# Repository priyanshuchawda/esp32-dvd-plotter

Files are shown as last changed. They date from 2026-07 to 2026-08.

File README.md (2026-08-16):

# ESP32 / Uno DVD Pen Plotter

DVD-drive sleds on an **HW-130 L293D** shield. Both boards are supported in
separate folders — swap hardware, keep the same G-code tools.

| Doc | Contents |
| --- | --- |
| [`docs/STATUS.md`](docs/STATUS.md) | Done vs left checklist |
| [`docs/ARCHITECTURE.md`](docs/ARCHITECTURE.md) | How the system fits together |
| [`FINDINGS.md`](FINDINGS.md) | Measured bed, steps/mm, coil ohms |
| [`hardware/WIRING.md`](hardware/WIRING.md) | **ESP32 jumper wiring** (no soldering) |
| [`cad/pcb/`](cad/pcb/) | **ESP32↔HW-130 adapter PCB** (Uno-style stack + Gerbers) |
| [`src/README.md`](src/README.md) | Firmware folder map |

Pipeline

## Firmware folders

| Path | Board |
| --- | --- |
| [`src/uno/uno_plotter`](src/uno/uno_plotter/) | Arduino Uno (shield stacked) |
| [`src/esp32/esp32_plotter`](src/esp32/esp32_plotter/) | ESP32 (jumpers into shield headers) |

Bed: **55 × 50 mm** · steps/mm: **2.058** · baud: **115200**

## ESP32 quick start (current focus)

1. Shield **off** the Uno. Power shield `5V`+`GND` and `EXT_PWR` (yellow jumper
   off). Common GND with ESP32. See [`hardware/WIRING.md`](hardware/WIRING.md).
2. Eight jumpers: D12/D4/D7/D8 + D11/D3/D6/D5 → ESP32 GPIOs in the wiring table.
3. Flash and test:

```bash
arduino-cli compile -b esp32:esp32:esp32 src/esp32/esp32_plotter
arduino-cli upload  -b esp32:esp32:esp32 -p /dev/ttyUSB0 src/esp32/esp32_plotter

# USB serial: $COILTEST then raise $POWER= if needed
tools/send_gcode.py -p /dev/ttyUSB0 -b 115200 test-square-uno.gcode
```

Wi-Fi hotspot `DVD-Plotter` / `plotter123` → draw in the browser.

## Uno quick start

```bash
arduino-cli compile -b arduino:avr:uno src/uno/uno_plotter
arduino-cli upload  -b arduino:avr:uno -p /dev/ttyACM0 src/uno/uno_plotter
tools/send_gcode.py -p /dev/ttyACM0 -b 115200 test-square-uno.gcode
```

## Making G-code

| Tool | Use |
| --- | --- |
| [`tools/text2gcode.py`](tools/text2gcode.py) | Hershey single-stroke text |
| [`tools/handwriting2gcode.py`](tools/handwriting2gcode.py) | Neural handwriting |
| [`tools/image2gcode.py`](tools/image2gcode.py) | Bitmap → outlines |
| [`tools/send_gcode.py`](tools/send_gcode.py) | USB stream |
| `python3 sim/simulate.py job.gcode --paper` | Paper preview |

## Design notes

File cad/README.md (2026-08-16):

# Mechanical CAD

[`plotter.scad`](plotter.scad) is a parametric model of the whole machine.
[`pcb/`](pcb/) is the **ESP32 ↔ HW-130 adapter** KiCad project (Uno-form stack).

Bed defaults match this build’s measurements (**55 × 50 mm**). Other sled
dimensions are still estimates — measure your chassis before cutting or
printing.

## Render and export

```bash
mkdir -p cad/out

# Whole machine (PNG)
openscad -D 'part="assembly"' --imgsize=1200,900 \
  --camera=120,110,70,55,0,30,480 \
  -o cad/out/assembly.png cad/plotter.scad

# Printable parts
openscad -D 'part="pen_lift"' -o cad/out/pen_lift.stl cad/plotter.scad
openscad -D 'part="paper_bed"' -o cad/out/paper_bed.stl cad/plotter.scad
openscad -D 'part="gantry_upright"' -o cad/out/gantry_upright.stl cad/plotter.scad
```

Valid `part` values: `assembly`, `pen_lift`, `paper_bed`, `gantry_upright`.

Confirm manifold solids after edits:

```bash
openscad -D 'part="pen_lift"' -o /tmp/check.stl cad/plotter.scad 2>&1 | grep Simple
```

`Simple: yes` means a valid printable solid.

## Layout

Y sled moves the paper front/back; X sled is overhead and moves the pen
left/right. Usable drawing area is the paper bed: **55 × 50 mm** on this frame
(`sled_travel_x` / `sled_travel_y` / `bed_x` / `bed_y` in the SCAD file).

## Pen bracket

Bolts to the X carriage and hangs down. Guide tube, SG90 cradle, and screw
strip are stacked so they do not overlap. A rubber band can provide pen
down-force; the servo horn lifts the collar.

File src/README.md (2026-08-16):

# Firmware layout

| Path | Board | Notes |
| --- | --- | --- |
| [`uno/uno_plotter`](uno/uno_plotter/) | Arduino Uno | Stock AFMotor + HW-130 (stacked) |
| [`uno/uno_motor_test`](uno/uno_motor_test/) | Arduino Uno | Jog / bring-up |
| [`esp32/esp32_plotter`](esp32/esp32_plotter/) | ESP32 | 74HC595 via jumpers — **active ESP path** |
| [`esp32/legacy_bypass`](esp32/legacy_bypass/) | ESP32 | Old solder-bypass firmware (archived) |

Wiring for ESP32 jumpers: [`../hardware/WIRING.md`](../hardware/WIRING.md).

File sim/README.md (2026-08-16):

# Simulation

Two independent layers. The first needs nothing but Python; the second emulates
the real ESP32 running the actual compiled binary.

## Layer 1: toolpath simulation (no hardware, no accounts)

`firmware_model.py` is a line-by-line port of the motion logic in
[`../src/esp32_l293d_plotter.ino`](../src/esp32_l293d_plotter.ino): the same
Bresenham interleave, the same `lroundf` step rounding, the same four-phase
coil table. The Uno plotter uses the same G-code dialect and Bresenham idea, so
the same preview works for Uno jobs if you pass the calibrated steps/mm.

**Uno defaults (measured):** bed 55×50 mm, **2.058** steps/mm on X and Y.

```bash
# Uno square (current hardware)
python3 sim/simulate.py test-square-uno.gcode \
  --envelope 55 --steps-x 2.058 --steps-y 2.058 \
  --out sim/out/uno_square.png

# Any job — always match firmware $STEPSX/$STEPSY and bed
python3 sim/simulate.py myart.gcode \
  --envelope 55 --steps-x 2.058 --steps-y 2.058 \
  --out sim/out/preview.png
```

It writes a PNG to `sim/out/` showing the drawn path, the pen-up travel moves,
the usable envelope, and the coil waveforms. It exits non-zero and prints
warnings when a job leaves the envelope, ends with the pen down, or uses a
command the firmware would reject.

Use it before sending any new artwork to real hardware. It costs nothing and
catches scaling and travel mistakes that would otherwise crash the carriage
into an end stop.

**Keep this file in sync with the firmware.** If the motion code changes, the
model must change too, or the simulation stops being meaningful.

## Layer 2: firmware emulation (Wokwi)

This runs the actual compiled binary on an emulated ESP32 and captures the real
GPIO transitions, so it validates the shipped firmware rather than a model of
it. Relevant once you leave the Uno path.

Install once:

```bash
curl -sSL https://wokwi.com/ci/install.sh | sh
```

It needs a free token from <https://wokwi.com/dashboard/ci>:

```bash
export WOKWI_CLI_TOKEN=your_token_here
```

Build, stage the binary, then run:

```bash
arduino-cli compile --fqbn esp32:esp32:esp32 --build-path /tmp/esp32-dvd-plotter-build .
mkdir -p build
cp /tmp/esp32-dvd-plotter-build/esp32-dvd-plotter.ino.{merged.bin,elf} build/
wokwi-cli . --timeout 10000 --serial-log-file build/serial.log
```

[`../diagram.json`](../diagram.json) wires a logic analyzer to the eight
direction GPIOs, so `--vcd-file` exports the real coil waveforms for inspection:

```bash
wokwi-cli . --timeout 20000 --vcd-file build/coils.vcd
```

`wokwi-cli lint` validates the diagram without a token. It already caught that
GPIO16 and GPIO17 are exposed as `RX2` and `TX2` on a 30-pin DevKit.

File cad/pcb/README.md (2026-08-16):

# ESP32 ↔ HW-130 adapter PCB

Uno-form adapter so the **HW-130 stacks like on an Arduino Uno**, while the
**ESP32-DevKit** plugs in beside it (right wing — not under the shield).

| | |
| --- | --- |
| KiCad project | [`esp32_hw130_adapter/`](esp32_hw130_adapter/) |
| Regenerator | [`generate_adapter.py`](generate_adapter.py) |
| Gerbers | [`out/gerbers.zip`](out/gerbers.zip) |
| Preview | [`out/adapter_top.png`](out/adapter_top.png) |
| Pin map | [`out/pinmap.md`](out/pinmap.md) |
| BOM | [`BOM.md`](BOM.md) |

**Board size ≈ 121 × 94 mm · 2-layer · DRC clean (0 errors)**

## How it works

```text
┌─────────────────────────────┬──────────────────────┐
│  Arduino R3 male headers    │  ESP32 DevKit        │
│  HW-130 stacks here         │  2×15 female sockets │
│  (same as Uno)              │  USB ↑               │
│                             │                      │
│  J_5V ── external 5 V       │                      │
└─────────────────────────────┴──────────────────────┘
```

Traces match firmware [`src/esp32/esp32_plotter`](../../src/esp32/esp32_plotter/):

| Shield | ESP32 |
| --- | --- |
| D12 | GPIO18 |
| D4 | GPIO19 |
| D7 | GPIO23 |
| D8 | GPIO13 |
| D11 | GPIO25 |
| D3 | GPIO26 |
| D6 | GPIO27 |
| D5 | GPIO32 |
| D10 (SERVO_1) | GPIO33 |
| 5V / GND | J_5V only |

## Open / rebuild

```bash
# GUI
kicad cad/pcb/esp32_hw130_adapter/esp32_hw130_adapter.kicad_pro

# Regenerate PCB from script (needs KiCad’s python3.14 + pcbnew)
python3.14 cad/pcb/generate_adapter.py
```

## Order / assemble

1. Upload [`out/gerbers.zip`](out/gerbers.zip) to any PCB fab (JLCPCB, PCBWay, …).
2. Solder parts from [`BOM.md`](BOM.md).
3. Plug ESP32 into the wing; stack HW-130 on the left headers.
4. Remove yellow **PWR** jumper; motors on `EXT_PWR`; logic 5 V into **J_5V**.
5. Flash `src/esp32/esp32_plotter` and run `$COILTEST`.

Until the PCB arrives, use Dupont jumpers — same nets — see
[`hardware/WIRING.md`](../../hardware/WIRING.md).

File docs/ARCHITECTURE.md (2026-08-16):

# Architecture

How the pieces connect on the **current Uno path**, and what is deferred.

## System overview

```mermaid
flowchart TB
  subgraph host [Laptop]
    T[text2gcode / handwriting2gcode / image2gcode]
    S[sim/simulate.py --paper]
    U[send_gcode.py]
    T --> S
    S -->|PNG looks good| U
  end

  subgraph controller [Arduino Uno]
    F[uno_plotter firmware]
    AF[AFMotor + 74HC595]
    F --> AF
  end

  subgraph machine [DVD frame]
    X[X sled M1/M2]
    Y[Y sled M3/M4]
    P[SG90 SERVO_1 optional]
  end

  U -->|USB 115200| F
  AF --> X
  AF --> Y
  F --> P
```

## Software pipeline

```mermaid
flowchart LR
  A[Text / image / strokes] --> B[G-code]
  B --> C{simulate.py}
  C -->|warnings| A
  C -->|ok| D[send_gcode.py]
  D --> E[Uno plotter]
  E --> F[Sleds move]
```

## Coordinate system

```text
Y 50 mm
^
|
|   paper / bed 55 × 50 mm
|
+--------------> X 55 mm
(0,0) = corner where sleds are parked at power-on / G92
```

Origin is a **corner**, not the middle of the rails.

## Firmware roles

| Sketch | Baud | Use |
| --- | --- | --- |
| `src/uno_motor_test` | 9600 | Manual jog / wiring bring-up |
| `src/uno/uno_plotter` | 115200 | Uno + stacked HW-130 |
| `src/esp32/esp32_plotter` | 115200 + WiFi | ESP32 jumpers → 74HC595 (no solder) |

## Deferred ESP32 path

```mermaid
flowchart TB
  Phone[Phone browser WiFi UI] --> ESP[ESP32 firmware]
  ESP -->|GPIO to L293D| DRV[HW-130 L293D]
  ESP -.->|D7 tied to 5V| OFF[74HC595 outputs Hi-Z]
  DRV --> MOTORS[X/Y steppers]
```

Do not start this until Uno ink plots are satisfactory. Tying `D7`→`5V`
disables the stock AFMotor path.

## CAD vs simulation

| Artifact | Answers |
| --- | --- |
| `cad/plotter.scad` | Will the frame / pen bracket fit? |
| `sim/simulate.py` | Will this G-code fit the bed and look right? |
| `sim/spice/` | Is coil current safe at a given step rate? |
| Watching sleds (no pen) | Do motors move / directions correct? |

Ink appearance without paper ≈ `simulate.py --paper`.

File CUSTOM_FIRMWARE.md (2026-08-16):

# Custom ESP32 firmware

> **Active sketch:** [`src/esp32/esp32_plotter`](src/esp32/esp32_plotter/) —
> drives the HW-130 **74HC595 with jumper wires** (no soldering).  
> Uno stays in [`src/uno/`](src/uno/). Wiring: [`hardware/WIRING.md`](hardware/WIRING.md).

The sketch announces itself over:

- USB serial at `115200` baud;
- Wi-Fi AP `DVD-Plotter` / `plotter123` (drawing UI);
- optional Bluetooth Classic as `DVD_Plotter` (`ENABLE_BLUETOOTH 1`).

Motors start disabled. First commands:

```text
$HELP
$STATUS
$COILTEST
$POWER=70
```

Then stream G-code with `tools/send_gcode.py` or the phone UI.

## Settings

| Command | Meaning |
| --- | --- |
| `$STEPSX=` / `$STEPSY=` | steps per mm (default 2.058 from Uno cal) |
| `$POWER=` | PWM duty on L293D enables (5–100) |
| `$INVERTX=` / `$INVERTY=` | flip axis direction |
| `$PENUP=` / `$PENDOWN=` | servo pulse µs |
| `$MOTORS=ON\|OFF` | enable / release |

## Flash

```bash
arduino-cli compile -b esp32:esp32:esp32 src/esp32/esp32_plotter
arduino-cli upload  -b esp32:esp32:esp32 -p /dev/ttyUSB0 src/esp32/esp32_plotter
```

Archived solder-bypass firmware: [`src/esp32/legacy_bypass/`](src/esp32/legacy_bypass/).

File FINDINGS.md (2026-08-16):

# Findings (Uno + HW-130 build)

Status as of the working bring-up on this frame. ESP32 + 74HC595 bypass is
deferred; finish drawing on the Uno first.

## Hardware that works

| Item | Result |
| --- | --- |
| Controllers | Arduino Uno + HW-130 (L293D) motor shield |
| Motors | DVD sled bipolar steppers (4 wires each) |
| Coil pairs (example motor) | Yellow–Green ~13.5 Ω, Blue–Purple ~13.3 Ω |
| Axes | X = shield M1+M2, Y = shield M3+M4 |
| Speed | Proven through **150 rpm** (AFMotor SINGLE) in square loops |
| Pen | Optional SG90 on shield **SERVO_1** (Arduino pin 10) — not required for dry-runs |
| Power for early tests | USB + yellow **PWR** jumper on (weak but OK unloaded) |

## Geometry

| Axis | Usable travel |
| --- | --- |
| X | **55 mm** (5.5 cm) |
| Y | **50 mm** (5.0 cm) |

Software origin is a **corner**, not the middle of the rails. Park both sleds
at the bottom-left of the paper, then `G92 X0 Y0` (or power-cycle with them
already there). G-code then lives in `0…55 × 0…50` mm.

## Calibration (steps/mm)

Default guess `6.667` was wrong for this pitch. Iterative `$CALX=10` / `$CALY=10`
with a ruler:

| Commanded | Measured | New steps/mm |
| --- | --- | --- |
| 10 mm | 18 mm | 3.704 |
| 10 mm | 15 mm | 2.469 |
| 10 mm | 12 mm | 2.058 |
| 10 mm | **10 mm** | **2.058** (kept) |

Firmware defaults in `src/uno/uno_plotter` are therefore:

```text
$STEPSX=2.058
$STEPSY=2.058
bed 55 x 50 mm
```

Resolution is about **0.49 mm per full step**. Fine handwriting will look
blocky; prefer larger characters or accept coarse strokes.

Formula if you recalibrate:  
`new = current × (commanded_mm / measured_mm)`.

## Firmware / tools

| Piece | Role |
| --- | --- |
| `src/uno/uno_motor_test` | Manual `x`/`y` jog for wiring bring-up |
| `src/uno/uno_plotter` | Uno G-code plotter @ **115200** |
| `src/esp32/esp32_plotter` | ESP32 G-code + WiFi UI (74HC595 jumpers) |
| `tools/uno_console.py` | Multi-command jog helper for the motor-test sketch |
| `tools/send_gcode.py` | Stream jobs over USB |
| `tools/text2gcode.py` | Hershey single-stroke text → G-code |
| `tools/handwriting2gcode.py` | Neural strokes → G-code (`setup_handwriting.sh` first) |
| `tools/image2gcode.py` | Bitmap → outlines → G-code |
| `sim/simulate.py` | Offline path preview (use before paper) |

## Simulation (no hardware)

Until pen and paper exist, treat `sim/simulate.py --paper` as the stand-in for a finished page. Defaults are already the measured 55×50 mm bed and 2.058 steps/mm.

## Simulation commands

Always pass the calibrated bed and steps:

```bash
python3 sim/simulate.py test-square-uno.gcode \
  --envelope 55 --steps-x 2.058 --steps-y 2.058 \
  --out sim/out/preview.png
```

OpenSCAD (`cad/plotter.scad`) and Blender are for **mechanical design**, not
for checking whether a plot looks right. Use `sim/simulate.py` for that.

## ESP32

Jumper path (no soldering): [`hardware/WIRING.md`](hardware/WIRING.md) and
[`src/esp32/esp32_plotter`](src/esp32/esp32_plotter/). Uno folder stays usable —
unplug jumpers and restack the shield.

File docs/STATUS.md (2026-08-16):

# Project status

Last updated for the **ESP32 jumper path** (74HC595 kept; Uno folder still works).

## Done

| Area | Status |
| --- | --- |
| Motors identified as bipolar steppers | Done (~13 Ω coils) |
| Uno + HW-130 motion + calibration | Done — bed **55 × 50 mm**, steps/mm **2.058** |
| Uno G-code firmware | Done — `src/uno/uno_plotter` |
| ESP32 folder split | Done — `src/esp32/` vs `src/uno/` |
| ESP32 74HC595 jumper firmware | Done — `src/esp32/esp32_plotter` (no soldering) |
| Laptop G-code tools + simulator | Done |
| CAD / docs / diagrams | Done |

## In progress / next on hardware

| Item | What to do |
| --- | --- |
| ESP32 jumpers + 5 V logic supply | Follow [`hardware/WIRING.md`](../hardware/WIRING.md) |
| `$COILTEST` on ESP32 | Confirm each coil twitches |
| Dry-run square over USB / Wi-Fi | Same `test-square-uno.gcode` |
| Level shifter (only if flaky) | 4 channels on D12/D4/D7/D8 |

## Still waiting on parts

| Item | Why |
| --- | --- |
| SG90 pen lift | No servo yet — wire to SERVO_1 / GPIO33 |
| Real ink on paper | No pen/paper yet |

## Commands

```bash
# ESP32
arduino-cli compile -b esp32:esp32:esp32 src/esp32/esp32_plotter
arduino-cli upload  -b esp32:esp32:esp32 -p /dev/ttyUSB0 src/esp32/esp32_plotter

# Uno (anytime)
arduino-cli compile -b arduino:avr:uno src/uno/uno_plotter
arduino-cli upload  -b arduino:avr:uno -p /dev/ttyACM0 src/uno/uno_plotter
```

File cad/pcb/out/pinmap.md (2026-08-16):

# Pin map

| Shield pin | ESP32 |
| --- | --- |
| D12 | GPIO18 |
| D4 | GPIO19 |
| D7 | GPIO23 |
| D8 | GPIO13 |
| D11 | GPIO25 |
| D3 | GPIO26 |
| D6 | GPIO27 |
| D5 | GPIO32 |
| D10 | GPIO33 |
| 5V | J_5V external |
| GND | common |

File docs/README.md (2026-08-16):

# Docs assets

| File | Description |
| --- | --- |
| [STATUS.md](STATUS.md) | Done / not-done checklist |
| [ARCHITECTURE.md](ARCHITECTURE.md) | Mermaid system + pipeline diagrams |
| [out/pipeline.png](out/pipeline.png) | G-code → sim → Uno flow |
| [out/system.png](out/system.png) | Laptop → Uno → shield → sleds |
| [out/square_paper.png](out/square_paper.png) | Example paper preview (square) |
| [out/hi_paper.png](out/hi_paper.png) | Example paper preview (“hi”) |

Regenerate Graphviz PNGs:

```bash
dot -Tpng docs/pipeline.dot -o docs/out/pipeline.png
dot -Tpng docs/system.dot -o docs/out/system.png
```

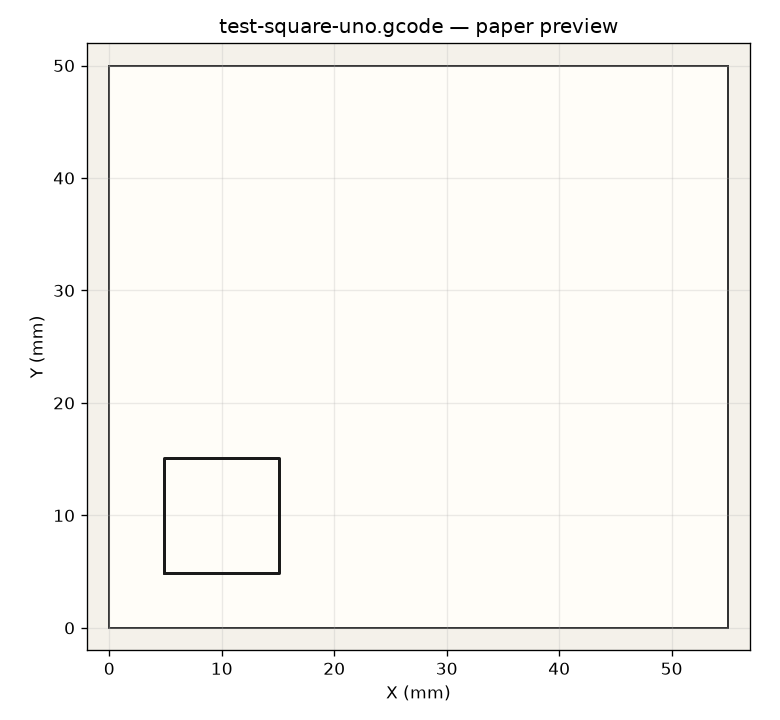
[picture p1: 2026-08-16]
docs/out/square_paper.png

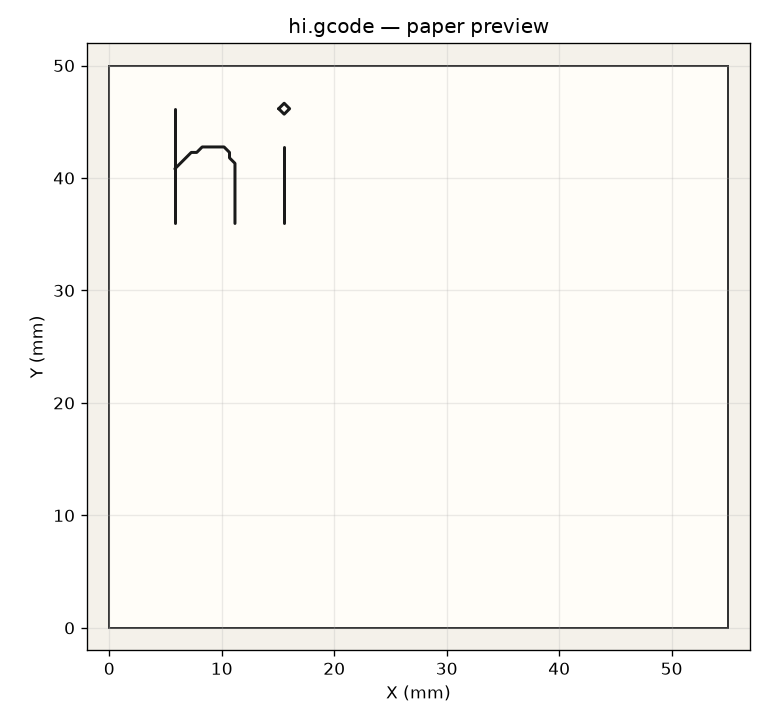
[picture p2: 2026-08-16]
docs/out/hi_paper.png

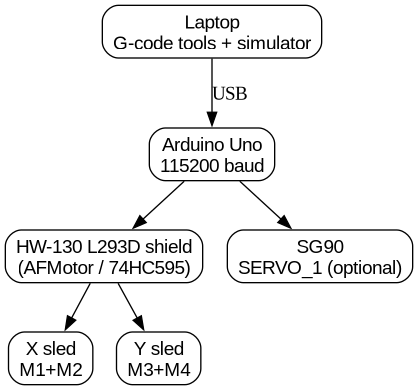
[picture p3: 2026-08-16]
docs/out/system.png

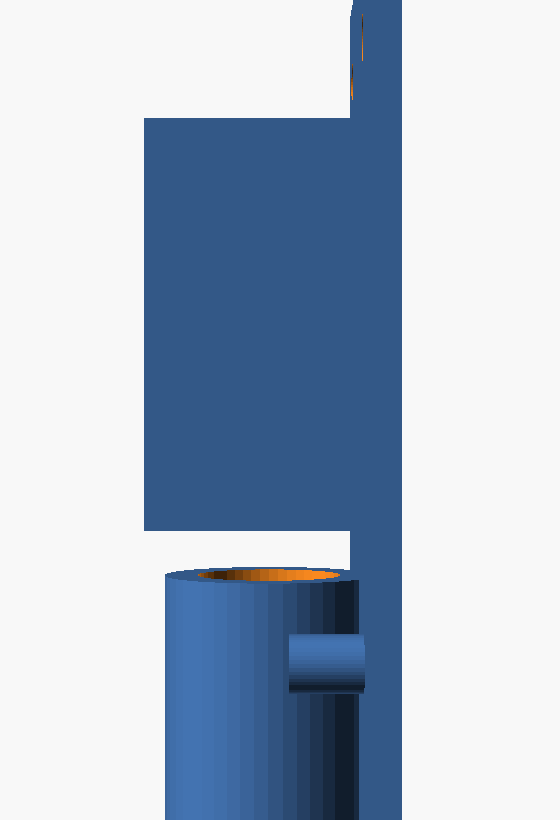
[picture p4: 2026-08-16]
cad/out/pen_lift_side.png

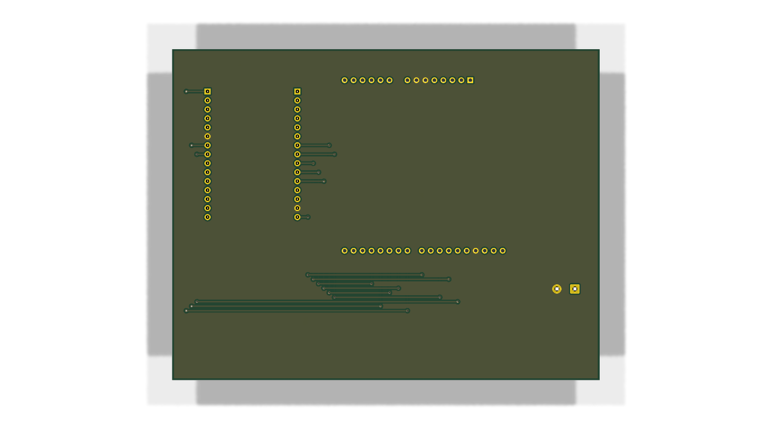
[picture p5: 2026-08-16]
cad/pcb/out/adapter_bottom.png

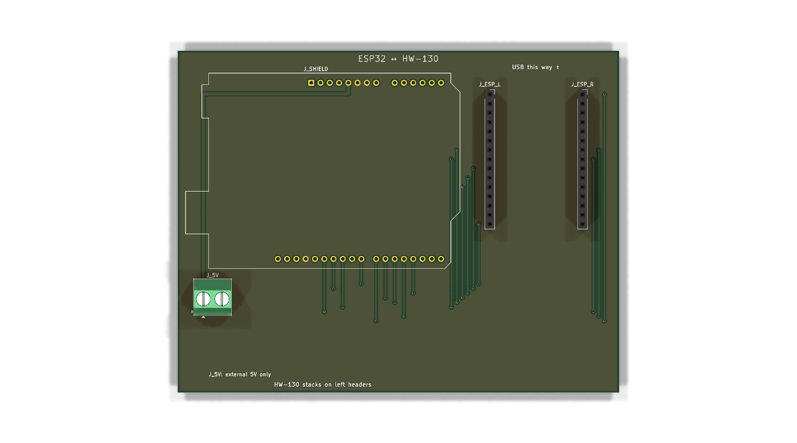
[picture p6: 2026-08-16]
cad/pcb/out/adapter_top.png

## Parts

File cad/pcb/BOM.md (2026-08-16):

# BOM — ESP32 ↔ HW-130 adapter

| Ref | Qty | Part |
| --- | --- | --- |
| J_SHIELD | 1 | Arduino R3 male header set (1×8 + 1×10 + 1×8 + 1×6) soldered into Uno footprint |
| J_ESP_L / J_ESP_R | 2 | 1×15 female pin socket 2.54 mm (ESP32-DevKit V1) |
| J_5V | 1 | 2-pin screw terminal 5.08 mm |
| H1–H4 | 0 | Optional M3 holes (add in pcbnew if you want standoffs) |
| — | 1 | PCB (this design) |
| — | 1 | ESP32-DevKit V1 / DOIT 30-pin |
| — | 1 | HW-130 L293D shield |
| — | 1 | Regulated 5 V supply (≥2 A recommended) |

## Assembly

1. Solder female sockets for ESP32 on the **right wing** (USB toward silk arrow).
2. Solder **male** Arduino headers pointing **up** on the left footprint.
3. Solder J_5V.
4. Plug ESP32 into wing sockets; stack HW-130 on male headers.
5. Wire motors as on Uno (X=M1+M2, Y=M3+M4). Remove yellow PWR jumper.
6. Feed J_5V from external 5 V; common GND with ESP32 USB GND / supply −.

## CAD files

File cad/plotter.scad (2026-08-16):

// Parametric frame for the ESP32 / DVD-drive pen plotter.
//
// Every dimension below is a starting estimate. Measure your own salvaged
// sleds and edit the values before cutting or printing anything.
//
//   openscad -D 'part="assembly"' -o out.png  cad/plotter.scad
//   openscad -D 'part="pen_lift"' -o pen.stl  cad/plotter.scad

part = "assembly"; // [assembly, pen_lift, paper_bed, gantry_upright]

/* [Measured DVD sled] */
sled_length      = 130;  // full length of the salvaged metal chassis
sled_width       = 42;
sled_height      = 12;
// Measured on this build: X travel ≈ 55 mm, Y ≈ 50 mm (see FINDINGS.md).
sled_travel_x    = 55;
sled_travel_y    = 50;
sled_travel      = sled_travel_x;  // legacy alias used by older layout code
carriage_length  = 30;
carriage_width   = 26;

/* [Frame] */
base_x           = 200;
base_y           = 190;
base_thickness   = 6;
upright_thickness = 6;
upright_width    = 26;

/* [Paper bed] — matches measured usable area */
bed_x            = 55;
bed_y            = 50;
bed_thickness     = 3;

/* [SG90 servo] */
servo_body_x     = 23.0;
servo_body_y     = 12.2;
servo_body_z     = 22.5;
servo_tab_span   = 32.5;
servo_tab_z      = 4.0;
servo_tab_thick  = 2.5;

/* [Pen] */
pen_diameter     = 10.0;
pen_clearance    = 0.4;
pen_plate_x      = 30;   // bracket back plate width
pen_tube_height  = 20;   // vertical guide the pen slides in
pen_gap          = 8;    // guide sits this far above the paper
pen_mount_zone   = 12;   // clear strip at the top for the carriage screws

/* [Print] */
wall             = 2.4;
$fn              = 48;

// Bracket geometry, derived so the three zones cannot overlap: guide tube at
// the bottom, servo cradle above it, bare screw strip at the top.
pen_bore     = pen_diameter + pen_clearance;
pen_axis_x   = pen_plate_x / 2;
// Sunk half a wall into the plate. Sitting it exactly against the face would
// make the tube tangent to the plate, which is not a manifold solid.
pen_axis_y   = wall / 2 + (pen_bore + 2 * wall) / 2;
cradle_h     = servo_body_z + 2 * wall;
cradle_z     = pen_tube_height + 4;
pen_plate_z  = cradle_z + cradle_h + pen_mount_zone;

// Height of the paper surface above the table.
bed_top          = base_thickness + sled_height + 4 + bed_thickness;
// The bracket bolts to the top of the X carriage and hangs down, so the rail
// height follows from the bracket rather than being guessed. Solving for
// "guide bottom sits pen_gap above the paper" keeps the two consistent when
// any sled dimension is edited.
carriage_top_off = sled_height + 4;
gantry_height    = bed_top + pen_plate_z + pen_gap - carriage_top_off;
carriage_top     = gantry_height + carriage_top_off;

module sled(travel_marker = false) {
    color("#9aa4ad") cube([sled_length, sled_width, sled_height]);
    color("#3d6fd8")
        translate([(sled_length - carriage_length) / 2,
                   (sled_width - carriage_width) / 2,
                   sled_height])
        cube([carriage_length, carriage_width, 4]);
    if (travel_marker)
        color("#d8a13d", 0.35)
            translate([(sled_length - sled_travel) / 2, 0, sled_height + 4])
            cube([sled_travel, sled_width, 0.6]);
}

module base_plate() {
    color("#c8b48a") cube([base_x, base_y, base_thickness]);
}

// Deliberately solid: paper needs continuous support right to the edges.
module paper_bed() {
    cube([bed_x, bed_y, bed_thickness]);
}

module gantry_upright() {
    difference() {
        cube([upright_width, upright_thickness, gantry_height]);
        // Slot lets the gantry height be trimmed after the bed is measured.
        translate([upright_width / 2, -1, gantry_height - 26])
            rotate([-90, 0, 0])
            hull() {
                cylinder(d = 4.5, h = upright_thickness + 2);
                translate([0, 16, 0]) cylinder(d = 4.5, h = upright_thickness + 2);
            }
    }
}

// Bracket that bolts to the X carriage. The pen slides vertically in a guide
// tube; a rubber band pulls it down onto the paper and the servo horn pushes
// a collar on the pen upward to lift it. Origin is the bottom of the guide.
module pen_lift() {
    difference() {
        union() {
            cube([pen_plate_x, wall, pen_plate_z]);

            // Guide tube, braced back to the plate.
            translate([pen_axis_x, pen_axis_y, 0])
                cylinder(d = pen_bore + 2 * wall, h = pen_tube_height);
            hull() {
                translate([pen_axis_x, pen_axis_y, 0])
                    cylinder(d = pen_bore + 2 * wall, h = 3);
                cube([pen_plate_x, wall, 3]);
            }

            // Servo cradle. Starts inside the plate so the union is solid
            // rather than two bodies meeting on a shared face.
            translate([(pen_plate_x - servo_body_x) / 2 - wall, 0, cradle_z])
                difference() {
                    cube([servo_body_x + 2 * wall,
                          wall + servo_body_y + wall,
                          cradle_h]);
                    translate([wall, wall, wall])
                        cube([servo_body_x, servo_body_y, cradle_h]);
                }

            // Rubber-band anchor, rooted in the plate so it is not a
            // free-floating body.
            translate([3, 0, pen_tube_height - 5])
                rotate([-90, 0, 0]) cylinder(d = 4, h = wall + 5);
        }

        // Pen bore, open top and bottom so the pen can protrude.
        translate([pen_axis_x, pen_axis_y, -1])
            cylinder(d = pen_bore, h = pen_tube_height + 2);

        // Mounting holes onto the DVD carriage, in the clear top strip.
        for (x = [5, pen_plate_x - 5])
            translate([x, -1, pen_plate_z - pen_mount_zone / 2])
                rotate([-90, 0, 0]) cylinder(d = 3.2, h = wall + 2);
    }
}

// The two axes must be perpendicular: the Y sled runs front-to-back carrying
// the paper, the X sled runs left-to-right overhead carrying the pen.
y_sled_x0 = (base_x - sled_width) / 2;
y_sled_y0 = (base_y - sled_length) / 2;
x_sled_x0 = (base_x - sled_length) / 2;
x_sled_y0 = (base_y - sled_width) / 2;

module assembly() {
    base_plate();

    // Y axis, long axis along Y.
    translate([y_sled_x0 + sled_width, y_sled_y0, base_thickness])
        rotate([0, 0, 90]) sled(travel_marker = true);
    translate([(base_x - bed_x) / 2, (base_y - bed_y) / 2,
               base_thickness + sled_height + 4])
        color("#f2efe6") paper_bed();

    // Uprights stand under the two ends of the X rail, and must clear the
    // full width of the Y sled between them.
    for (x = [x_sled_x0 + 4, x_sled_x0 + sled_length - upright_width - 4])
        translate([x, (base_y - upright_thickness) / 2, base_thickness])
            color("#c8b48a") gantry_upright();

    // X axis, long axis along X, sitting on the uprights.
    translate([x_sled_x0, x_sled_y0, gantry_height])
        sled(travel_marker = true);

    // Pen bracket bolts to the X carriage and hangs toward the operator.
    translate([base_x / 2 - pen_plate_x / 2, x_sled_y0 - wall,
               carriage_top - pen_plate_z])
        color("#4fb06a") pen_lift();

    // The pen itself, shown reaching the paper.
    color("#22252b")
        translate([base_x / 2, x_sled_y0 - wall + pen_axis_y, bed_top])
        cylinder(d = pen_diameter, h = pen_gap + pen_tube_height + 12);
}

if      (part == "assembly")        assembly();
else if (part == "pen_lift")        pen_lift();
else if (part == "paper_bed")       paper_bed();
else if (part == "gantry_upright")  gantry_upright();

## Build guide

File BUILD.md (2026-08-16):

# Building the ESP32 DVD pen plotter

> **Firmware lives in two folders now:** [`src/uno/`](src/uno/) and
> [`src/esp32/esp32_plotter/`](src/esp32/esp32_plotter/).  
> ESP32 uses **jumper wires into the shield headers** (74HC595 stays). See
> [`hardware/WIRING.md`](hardware/WIRING.md). This file is the longer build
> narrative; quick start is in the README.

This follows the same idea as the popular CD-ROM plotter tutorials, but three
of their five phases do not work on an ESP32 and are replaced here.

| Tutorial step | Why it does not apply | What we do instead |
| --- | --- | --- |
| Adafruit Motor Shield library | AVR-only: direct port and timer register access, will not compile for ESP32 | Custom firmware in `src/` |
| Inkscape 0.48 + Unicorn plugin | From 2011, 32-bit Windows only, uninstallable today | `tools/image2gcode.py`, calling potrace |
| Pronterface | GUI, not installed, no safe-abort | `tools/send_gcode.py` |
| Wiring through the shield headers | Signals pass through a 5 V 74HC595 the 3.3 V ESP32 cannot drive reliably | Bypass the '595, wire straight to the L293D |
| 7.5–9 V supply | Correct in principle, but the right voltage depends on your coil resistance | Measure, then compute (Phase 1) |

---

## Phase 0 — Confirm your motors are steppers

**Do not skip this. Everything else depends on it.**

Many DVD drives move the laser sled with a *brushed DC motor*, not a stepper.
They get away with it because the drive reads its position off the disc in a
closed loop. A brushed motor cannot be positioned open-loop, so if that is what
you have, no firmware or wiring will make this work.

Two tests:

1. **Turn the lead screw slowly by hand.** A stepper resists in distinct
   clicks, one detent at a time. A brushed motor turns smoothly with none.
   This is the more reliable test.
2. **Count the motor's wires.** Four means bipolar stepper. Two means brushed
   DC. Ignore the wide ribbon going to the laser pickup.

Then identify the coil pairs. Set your meter to resistance and measure all six
combinations of the four wires:

| Pair | Reading | Meaning |
| --- | --- | --- |
| 1-2, 1-3, 1-4, 2-3, 2-4, 3-4 | two pairs read 10–30 Ω | those two pairs are your coils |
| | the other four read `OL` | no connection, as expected |

Write down the resistance. Phase 1 needs it.

---

## Phase 1 — Power

Motors cannot run from the ESP32's USB. Two steppers plus a servo draw well
over an amp; USB gives you half that. The rail sags, the ESP32 brownout-resets
mid-plot, and you spend days chasing a firmware bug that is not there.

The L293D drops about 1.8 V internally, so the coil only sees
`V_supply − 1.8`. Coil current is therefore:

```
I = (V_supply − 1.8) / R_coil
```

Aim for **250–450 mA**. Above 600 mA the L293D exceeds its rating and
overheats; below about 200 mA there is not enough torque and the motor skips.

| Coil resistance | 5 V | 6 V | 7.5 V | 9 V | 12 V |
| --- | --- | --- | --- | --- | --- |
| 10 Ω | 320 mA | 420 mA | 570 mA | **720 mA** | **1020 mA** |
| 15 Ω | 213 mA | 280 mA | 380 mA | 480 mA | **680 mA** |
| 20 Ω | 160 mA | 210 mA | 285 mA | 360 mA | 510 mA |
| 30 Ω | 107 mA | 140 mA | 190 mA | 240 mA | 340 mA |

Bold values exceed the L293D's 600 mA limit. Pick the lowest voltage that
lands you in the 250–450 mA band. This is why a blanket "use 9 V" is wrong: at
10 Ω it destroys the chip, at 30 Ω it is barely adequate.

After a few minutes of running, touch the motors. If they are too hot to hold
comfortably, drop a volt. The coils stay energised during a plot.

### If you have not measured the coils

You do not have to. The firmware chops the L293D enable pins at 20 kHz, so the
average coil current is set in software rather than purely by Ohm's law. That
turns an irreversible hardware guess into an adjustable dial.

`$POWER=` takes 5 to 100 percent and defaults to a deliberately timid 45,
which is safe at any coil resistance you are realistically going to find.

Wire up a 6 V or 7.5 V supply, then walk it up:

```
> $POWER=45
> G1 X10 F200      # does it move cleanly?
> $POWER=55        # if it stalls or skips, raise and retry
```

Stop as soon as movement is reliable. Every extra percent is heat you do not
need. Give it a few minutes and feel the motors and the L293D chips; if either
is too hot to keep a finger on, come back down.

Measuring still gives a better result, because it lets you pick the right
supply voltage instead of throwing away the excess as heat, and it makes the
step-rate figures below real rather than estimated. But it is no longer a
prerequisite for switching on.

> **Remove the power jumper on the shield.** The HW-130 has a jumper tying the
> motor supply to the logic 5 V rail. Leave it in with an external supply and
> you push 9 V into the ESP32's 5 V pin and destroy the board. Take it off
> before connecting anything.

Supply and ESP32 must share a common ground.

---

## Phase 2 — Wiring

The shield's Arduino headers route the four direction signals through an
onboard 74HC595 shift register running at 5 V. Its guaranteed HIGH threshold
is about 3.5 V and the ESP32 outputs 3.3 V. That is below spec: it often works
on the bench and then randomly drops steps or reverses a motor.

Bypassing it costs nothing, because the L293D itself only needs 2.3 V for a
HIGH. Pull the 74HC595 out of its socket and drive the socket contacts, which
connect straight to the L293D inputs.

| Signal | Socket pin | ESP32 GPIO | DevKit silkscreen |
| --- | --- | --- | --- |
| X coil 1 A | 2 | GPIO16 | `RX2` |
| X coil 1 B | 3 | GPIO17 | `TX2` |
| X coil 2 A | 1 | GPIO18 | `D18` |
| X coil 2 B | 4 | GPIO19 | `D19` |
| Y coil 1 A | 5 | GPIO21 | `D21` |
| Y coil 1 B | 7 | GPIO22 | `D22` |
| Y coil 2 A | 15 | GPIO23 | `D23` |
| Y coil 2 B | 6 | GPIO13 | `D13` |
| Ground | 8 | `GND` | |

**Never connect anything to socket pin 16** — that is the '595's Vcc.

Enable lines go to the shield's PWM pads, and the servo to any free pin:

| Function | Shield pad | ESP32 GPIO |
| --- | --- | --- |
| Enable M1 | D11 | GPIO25 |
| Enable M2 | D3 | GPIO26 |
| Enable M3 | D6 | GPIO27 |
| Enable M4 | D5 | GPIO32 |
| Servo signal | — | GPIO33 |

Motors go to the screw terminals: **X axis to M1 and M2, Y axis to M3 and M4**,
one coil pair per terminal block, centre pin unused. Servo brown to ground, red
to 5 V, orange to GPIO33. Reversing the servo's red and brown will destroy it.

Full detail is in [`hardware/WIRING.md`](hardware/WIRING.md).

---

## Phase 3 — Flash the firmware

WiFi and the web UI need the larger partition, so the `PartitionScheme`
argument is not optional.

```bash
arduino-cli core install esp32:esp32          # once
arduino-cli compile --fqbn esp32:esp32:esp32:PartitionScheme=huge_app .
arduino-cli upload  --fqbn esp32:esp32:esp32:PartitionScheme=huge_app \
    -p /dev/ttyUSB0 .
```

If `/dev/ttyUSB0` is missing, check `lsusb` for a CP210x or CH340, and confirm
you are in the `dialout` group with `id -nG`.

Then open a console:

```bash
tools/send_gcode.py --console
> $HELP
> $STATUS
```

Motors start disabled deliberately, so nothing moves until you ask.

---

## Phase 4 — Calibrate

Do this with the pen removed or lifted.

**Check the wiring first.** Before commanding any movement:

```
> $COILTEST
```

This drives each of the eight H-bridge outputs alone for 600 ms. You should
feel exactly eight distinct twitches, four per motor. A missing twitch means
that half-bridge or its wire is dead. Two outputs moving the same coil means a
pair is split across the two terminal blocks, which is the usual reason a
motor buzzes without turning.

**Check direction.** Centre both carriages by hand, then:

```
> $MOTORS=ON
> G92 X0 Y0
> G1 X10 F200
```

X should move 10 mm in the direction you want to call positive. If it moves
backward, swap either coil pair of that motor at the screw terminal. If it
buzzes without moving, you have the pairs wrong: the two wires of one coil are
split across both terminals.

**Set steps per mm.** Command a known move and measure what you actually got
with a ruler:

```
> G92 X0 Y0
> G1 X20 F200
```

If 20 mm was commanded but you measured 18 mm, correct the current value:

```
new = old × (commanded ÷ measured) = 6.667 × (20 ÷ 18) = 7.41
> $STEPSX=7.41
```

Repeat until they agree, then do Y. These settings live in RAM, so note them
down and edit the defaults in `src/esp32_l293d_plotter.ino`.

**Set the pen servo.** `$PENUP=` and `$PENDOWN=` take microseconds, 500–2500:

```
> $PENDOWN=1600
> M300 S30
> $PENUP=1000
> M300 S50
```

The pen should just kiss the paper when down, not press. `$PENSETTLE=250` is
how long movement pauses for the servo to travel; raise it if the pen drags a
line as it lifts.

---

## Phase 5 — Turn an image into G-code

```bash
tools/image2gcode.py drawing.png -o drawing.gcode
```

It thresholds the image, traces it with potrace (the same engine behind
Inkscape's Trace Bitmap), reduces the points, orders the paths to cut pen-up
travel, and fits everything to the bed.

Useful options:

| Option | Purpose |
| --- | --- |
| `--width`, `--height` | bed size in mm, default 35 |
| `--threshold` | 0–255; raise it to capture more of the image as ink |
| `--invert` | for light drawings on dark backgrounds |
| `--simplify` | higher means fewer points and faster plots |
| `--feed` | drawing speed, mm/min |

Line art and high-contrast logos work well. Photographs do not: tracing gives
thousands of nested outlines.

**Always simulate before plotting.** It costs a second and catches mistakes
while they are still free:

```bash
python3 sim/simulate.py drawing.gcode --out preview.png
```

Check the drawing fits the envelope and that the reported runtime is sane.

---

## Drawing from your phone

The firmware serves its own web page, so there is no app to install and it
works on Android, iOS, or a laptop equally.

By default the ESP32 hosts a hotspot. Connect your phone to **DVD-Plotter**
with password `plotter123`, then open **http://192.168.4.1**. Draw with your
finger and press Plot.

The drawback is that your phone loses its internet connection while joined to
the plotter. To avoid that, have the ESP32 join your own network instead by
filling in the credentials near the top of `src/esp32_l293d_plotter.ino`:

```cpp
const char *WIFI_SSID = "your-network";
const char *WIFI_PASSWORD = "your-password";
```

It then prints its address over USB serial at boot; browse to that instead.

The page simplifies each stroke before sending, because a finger drag produces
hundreds of nearly collinear points and every one would otherwise become a
separate move for the board to chew through. Stop halts the plot, lifts the
pen, and releases the motors.

Bluetooth is compiled out by default. Both radios do fit together, but they
share one antenna and coexistence costs stability, and the drawing UI only
needs WiFi. Set `ENABLE_BLUETOOTH` to 1 in the firmware if you also want
serial-terminal control.

---

## Phase 6 — Plot

Centre both carriages by hand, because there are no endstops and the firmware
treats the power-on position as the origin.

```bash
tools/send_gcode.py drawing.gcode
```

Scribble on scrap paper first to get the ink flowing. Start with the pen lifted
for a dry run, then fit paper and run it for real.

Ctrl-C aborts safely: the pen lifts and the motors release. Never kill it any
other way, or the pen sits bleeding into the paper while the coils cook.

---

## Speed limits

The coil is an inductor, so current needs roughly three time constants to build
after the driver switches. Past that, faster stepping means less current and
less torque. From `sim/spice/`:

| Step rate | Torque available |
| --- | --- |
| 200–500 /s | 100% |
| 1000 /s | 98% |
| 2000 /s | 88% |
| 4000 /s | 73% |
| 8000 /s | 59% |

Stay near or below 1000 steps/s. Pushing past it does not draw faster, it skips
steps and shifts the drawing. Re-run `sim/spice/sweep.sh` once you know your
real coil resistance.

---

## When something goes wrong

| Symptom | Likely cause |
| --- | --- |
| Motor buzzes, does not turn | coil pairs split across terminals; re-check with the meter |
| Moves the wrong way | swap one coil pair on that motor |
| Drawing is skewed or short | steps per mm wrong, or stepping too fast for the torque |
| ESP32 resets mid-plot | motors drawing from USB, or the shield power jumper is still fitted |
| Pen drags on lift | raise `$PENSETTLE` |
| Everything freezes part-way | a line was never acknowledged; the sender prints which one |
| Motors very hot | supply voltage too high for your coil resistance, see Phase 1 |

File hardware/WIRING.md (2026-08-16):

# ESP32 + HW-130 wiring (no soldering)

Two firmwares, two folders — swap by unplugging:

| Folder | Board | Shield |
| --- | --- | --- |
| [`src/uno/`](../src/uno/) | Arduino Uno | Stacked on Uno (stock AFMotor) |
| [`src/esp32/esp32_plotter/`](../src/esp32/esp32_plotter/) | ESP32 DevKit | Jumpers into shield headers |

Nothing is removed from the HW-130. The 74HC595 stays. ESP32 bit-bangs the
same four control lines the Uno uses.

> Legacy solder-bypass notes live at the bottom. Prefer this jumper path.

## 1. Power (shield off the Uno)

| Branch | Connect | Do not |
| --- | --- | --- |
| Logic 5 V | shield `5V` + `GND` | ESP32 `5V` / `VIN` |
| Motors | shield `EXT_PWR` + / − | ESP32 |
| ESP32 | USB only while testing | — |

Remove the yellow `PWR` jumper on the shield. Tie **all grounds** together
(ESP32 GND, shield GND, supply −).

## 2. Jumper map (ESP32 → shield Arduino headers)

Plug DuPont wires into the **female** Arduino pin headers on top of the shield
(the same pads labelled D3, D4, …). Leave the 74HC595 untouched.

| Shield label | Function | ESP32 GPIO |
| --- | --- | --- |
| D12 | MOTORLATCH | **18** |
| D4 | MOTORCLK | **19** |
| D7 | MOTORENABLE (OE, active low) | **23** |
| D8 | MOTORDATA | **13** |
| D11 | M1 PWM enable | **25** |
| D3 | M2 PWM enable | **26** |
| D6 | M3 PWM enable | **27** |
| D5 | M4 PWM enable | **32** |
| SERVO_1 (signal) | pen servo (optional) | **33** |
| GND | common ground | **GND** |

Motors stay on the same terminals as the Uno path:

| Axis | Terminals |
| --- | --- |
| X | M1 + M2 |
| Y | M3 + M4 |

## 3. Bring-up

```bash
arduino-cli compile -b esp32:esp32:esp32 src/esp32/esp32_plotter
arduino-cli upload  -b esp32:esp32:esp32 -p /dev/ttyUSB0 src/esp32/esp32_plotter

# Serial (USB) — motors start disabled
# $COILTEST
# $POWER=70
# then stream G-code:
tools/send_gcode.py -p /dev/ttyUSB0 -b 115200 test-square-uno.gcode
```

Wi-Fi: board hosts hotspot `DVD-Plotter` / `plotter123` → open `http://192.168.4.1`.

If 3.3 V into the 74HC595 is flaky (missed steps / no motion), add a cheap
**4-channel level shifter** on D12/D4/D7/D8 only. PWM enables are fine at 3.3 V
(L293D VIH ≈ 2.3 V). That still needs **zero** changes to the shield.

## 5. Custom PCB (Uno-style stack)

A fabricated adapter lives in [`cad/pcb/`](../cad/pcb/):

- HW-130 stacks on Arduino R3 male headers (same as Uno)
- ESP32-DevKit plugs into a **side wing** (avoids crashing into the shield)
- Same pin map as the jumper table above
- Gerbers: `cad/pcb/out/gerbers.zip`

Until that board is made, use the jumpers in §2.

## 6. Switching back to Uno

1. Power off.
2. Unplug ESP32 (or the whole adapter).
3. Stack shield on Uno.
4. Use [`src/uno/uno_plotter`](../src/uno/uno_plotter/).

---

## Appendix: legacy solder bypass (not recommended)

Older notes that disable the 74HC595 and solder onto its legs live in git
history and [`src/esp32/legacy_bypass/`](../src/esp32/legacy_bypass/). That path
breaks Uno compatibility until rewired. Use jumpers instead.

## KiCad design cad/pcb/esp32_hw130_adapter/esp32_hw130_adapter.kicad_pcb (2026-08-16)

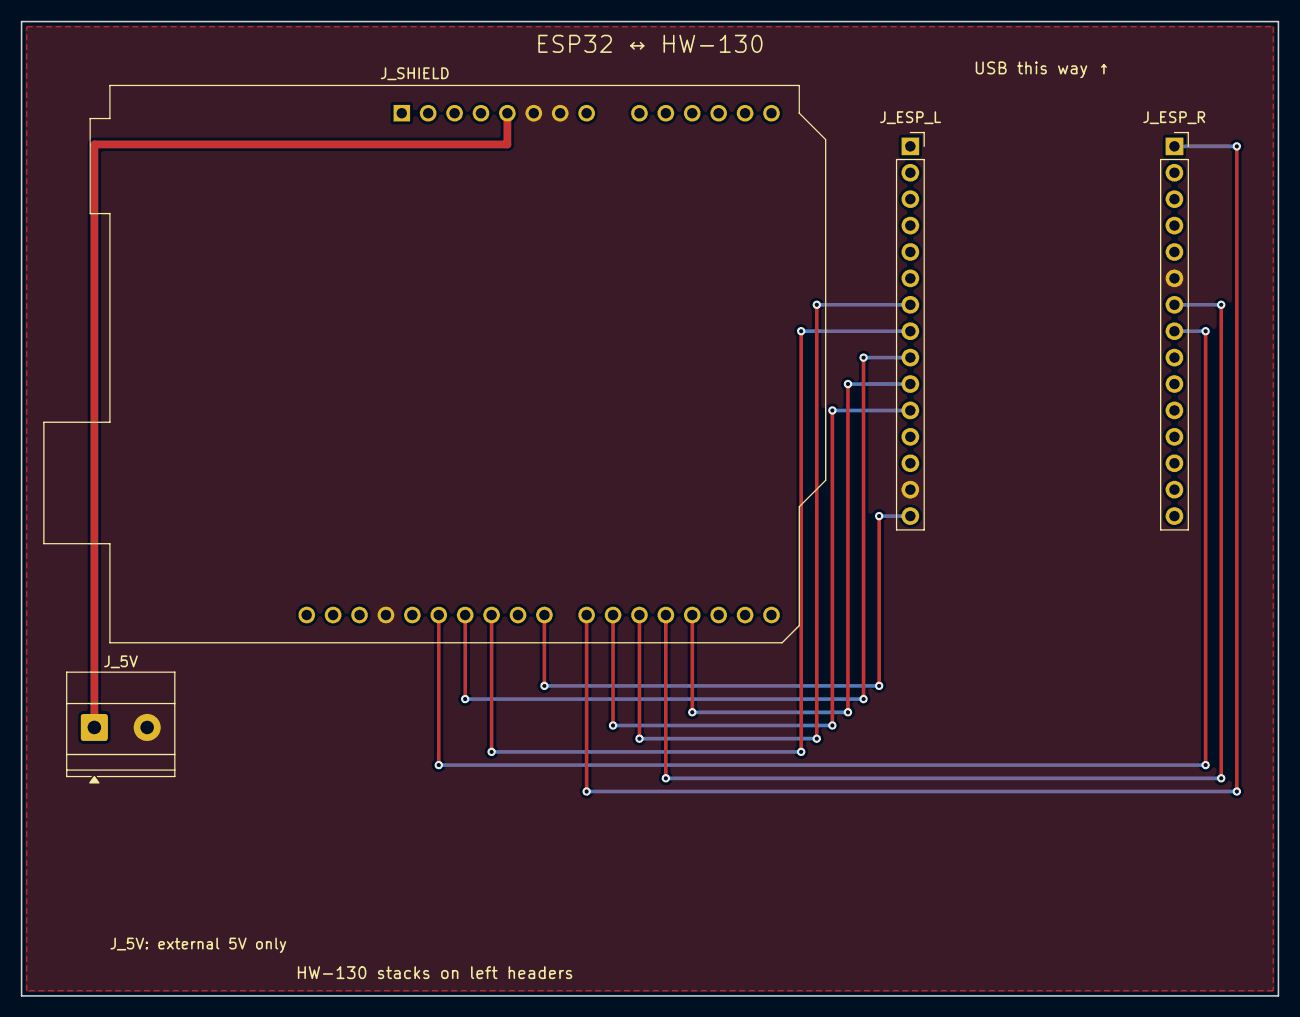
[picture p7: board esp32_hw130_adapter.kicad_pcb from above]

Board: 2 copper layers, 120.9 x 93.7 mm, 4 parts (0 on the bottom side), 11 nets.

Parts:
J_5V: EXT_5V; TerminalBlock_Phoenix_MKDS-1,5-2-5.08_1x02_P5.08mm_Horizont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
J_ESP_L: DevKit_LEFT; PinSocket_1x15_P2.54mm_Vertical
J_ESP_R: DevKit_RIGHT; PinSocket_1x15_P2.54mm_Vertical
J_SHIELD: UNO_R3_HEADERS; Arduino_UNO_R3

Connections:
GND: J_5V.2, J_ESP_L.14, J_ESP_R.6, J_SHIELD.6, J_SHIELD.7, J_SHIELD.29
GPIO13: J_ESP_L.15, J_SHIELD.23
GPIO18: J_ESP_R.8, J_SHIELD.27
GPIO19: J_ESP_R.7, J_SHIELD.19
GPIO23: J_ESP_R.1, J_SHIELD.22
GPIO25: J_ESP_L.9, J_SHIELD.26
GPIO26: J_ESP_L.10, J_SHIELD.18
GPIO27: J_ESP_L.11, J_SHIELD.21
GPIO32: J_ESP_L.7, J_SHIELD.20
GPIO33: J_ESP_L.8, J_SHIELD.25
P5V: J_5V.1, J_SHIELD.5

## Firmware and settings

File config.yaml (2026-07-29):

# FluidNC configuration for an original ESP32 DevKit and two HW-130
# A4988-compatible drivers. This is an initial, low-speed commissioning config.
# Do not enable X/Y soft limits until the travel has been measured and homing
# switches have been installed or a repeatable manual-zero procedure is adopted.

name: "ESP32 DVD Pen Plotter"
board: "ESP32 DevKit"

stepping:
  engine: RMT
  idle_ms: 255
  pulse_us: 3
  dir_delay_us: 2
  disable_delay_us: 0

axes:
  # A4988 EN is active-low. Wire both driver EN pins to GPIO33.
  shared_stepper_disable_pin: gpio.33:low

  x:
    # Starting estimate for a common DVD mechanism at 1/8 microstepping.
    # Calibrate from measured travel before drawing.
    steps_per_mm: 53.333
    max_rate_mm_per_min: 400.000
    acceleration_mm_per_sec2: 20.000
    max_travel_mm: 35.000
    soft_limits: false
    motor0:
      stepstick:
        step_pin: gpio.25
        direction_pin: gpio.26

  y:
    steps_per_mm: 53.333
    max_rate_mm_per_min: 400.000
    acceleration_mm_per_sec2: 20.000
    max_travel_mm: 35.000
    soft_limits: false
    motor0:
      stepstick:
        step_pin: gpio.27
        direction_pin: gpio.14

  z:
    # A virtual 5 mm axis: Z0 and Z5 map to the two servo pulse endpoints.
    # Use test commands to find safe endpoints, then enable soft_limits.
    steps_per_mm: 100.000
    max_rate_mm_per_min: 300.000
    acceleration_mm_per_sec2: 20.000
    max_travel_mm: 5.000
    soft_limits: false
    motor0:
      rc_servo:
        output_pin: gpio.32
        pwm_hz: 50
        min_pulse_us: 1000
        max_pulse_us: 2000

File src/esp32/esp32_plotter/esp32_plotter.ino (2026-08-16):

#include <Arduino.h>
#include <ctype.h>
#include <math.h>

// ESP32 + HW-130 (L293D) via the stock 74HC595 path — no soldering.
// Jumpers from ESP32 GPIOs into the shield's Arduino female headers.
// Uno firmware stays in src/uno/; swap boards by unplugging jumpers / restacking.
//
//   arduino-cli compile -b esp32:esp32:esp32 src/esp32/esp32_plotter
//   arduino-cli upload  -b esp32:esp32:esp32 -p /dev/ttyUSB0 src/esp32/esp32_plotter
//
// Power: shield 5V + GND from a regulated 5 V supply (logic).
//        motors on EXT_PWR (yellow PWR jumper OFF). ESP32 from USB.
//        Common GND between ESP32, shield, and supply.

#define ENABLE_WIFI 1
#define ENABLE_BLUETOOTH 0

#if ENABLE_BLUETOOTH
#include <BluetoothSerial.h>
BluetoothSerial SerialBT;
#endif

#if ENABLE_WIFI
#include <WiFi.h>
#include <WebServer.h>
#include "web_ui.h"

const char *WIFI_SSID = "";
const char *WIFI_PASSWORD = "";
const char *AP_SSID = "DVD-Plotter";
const char *AP_PASSWORD = "plotter123";

constexpr float BED_W_MM = 55.0f;
constexpr float BED_H_MM = 50.0f;
constexpr size_t MAX_JOB_BYTES = 60000;

WebServer server(80);
String jobBuffer;
size_t jobCursor = 0;
bool jobActive = false;
#endif

// Shield Arduino-header labels → ESP32 GPIOs (jumper wires only).
// Same four control lines AFMotor uses on an Uno.
constexpr uint8_t PIN_MOTOR_LATCH = 18;   // D12
constexpr uint8_t PIN_MOTOR_CLK = 19;     // D4
constexpr uint8_t PIN_MOTOR_ENABLE = 23;  // D7  (74HC595 OE, active LOW)
constexpr uint8_t PIN_MOTOR_DATA = 13;    // D8

constexpr uint8_t PIN_PWM_M1 = 25;  // D11
constexpr uint8_t PIN_PWM_M2 = 26;  // D3
constexpr uint8_t PIN_PWM_M3 = 27;  // D6
constexpr uint8_t PIN_PWM_M4 = 32;  // D5
constexpr uint8_t PIN_SERVO = 33;   // SERVO_1 signal (or D9/D10 pad)

// AFMotor bit positions inside the 74HC595 latch byte.
constexpr uint8_t BIT_M1_A = 2;
constexpr uint8_t BIT_M1_B = 3;
constexpr uint8_t BIT_M2_A = 1;
constexpr uint8_t BIT_M2_B = 4;
constexpr uint8_t BIT_M3_A = 5;
constexpr uint8_t BIT_M3_B = 7;
constexpr uint8_t BIT_M4_A = 0;
constexpr uint8_t BIT_M4_B = 6;

constexpr uint8_t FULL_SPEED_PWM = 255;
constexpr uint32_t ENABLE_PWM_HZ = 20000;
constexpr float RAPID_FEED_MM_MIN = 300.0f;
constexpr float DEFAULT_FEED_MM_MIN = 180.0f;
constexpr uint32_t MIN_STEP_INTERVAL_US = 2000;
constexpr uint16_t SERVO_FREQUENCY_HZ = 50;
constexpr uint8_t SERVO_RESOLUTION_BITS = 16;

uint8_t latchState = 0;

void latchTx() {
  digitalWrite(PIN_MOTOR_LATCH, LOW);
  for (uint8_t i = 0; i < 8; ++i) {
    digitalWrite(PIN_MOTOR_CLK, LOW);
    digitalWrite(PIN_MOTOR_DATA, (latchState & (1u << (7 - i))) ? HIGH : LOW);
    digitalWrite(PIN_MOTOR_CLK, HIGH);
  }
  digitalWrite(PIN_MOTOR_LATCH, HIGH);
  digitalWrite(PIN_MOTOR_LATCH, LOW);
}

void shiftBegin() {
  pinMode(PIN_MOTOR_LATCH, OUTPUT);
  pinMode(PIN_MOTOR_CLK, OUTPUT);
  pinMode(PIN_MOTOR_ENABLE, OUTPUT);
  pinMode(PIN_MOTOR_DATA, OUTPUT);
  latchState = 0;
  latchTx();
  digitalWrite(PIN_MOTOR_ENABLE, LOW);  // enable 74HC595 outputs
}

// AFMotor SINGLE-style bipolar sequence (matches Uno calibration).
struct ShieldStepper {
  uint8_t bitA;  // coil 1 A
  uint8_t bitB;  // coil 2 A
  uint8_t bitC;  // coil 1 B
  uint8_t bitD;  // coil 2 B
  uint8_t phase = 0;
  int32_t positionSteps = 0;

  void clearBits() {
    latchState &= ~((1u << bitA) | (1u << bitB) | (1u << bitC) | (1u << bitD));
  }

  void release() {
    clearBits();
    latchTx();
  }

  void applyPhase() {
    clearBits();
    switch (phase & 0x03) {
      case 0: latchState |= (1u << bitA); break;
      case 1: latchState |= (1u << bitB); break;
      case 2: latchState |= (1u << bitC); break;
      default: latchState |= (1u << bitD); break;
    }
    latchTx();
  }

  void step(int8_t direction) {
    phase = (phase + (direction > 0 ? 1 : 3)) & 0x03;
    positionSteps += direction > 0 ? 1 : -1;
    applyPhase();
  }
};

ShieldStepper xMotor {BIT_M1_A, BIT_M2_A, BIT_M1_B, BIT_M2_B};  // M1+M2
ShieldStepper yMotor {BIT_M3_A, BIT_M4_A, BIT_M3_B, BIT_M4_B};  // M3+M4

// Same calibration as Uno (FINDINGS.md). Re-check after swapping boards.
float stepsPerMmX = 2.058f;
float stepsPerMmY = 2.058f;
float bedMaxX = 55.0f;
float bedMaxY = 50.0f;
float feedRateMmMin = DEFAULT_FEED_MM_MIN;
float xPositionMm = 0.0f;
float yPositionMm = 0.0f;
float unitScaleMm = 1.0f;
bool absoluteMode = true;
bool motorsEnabled = false;
uint8_t motorPowerPercent = 70;
uint16_t penUpUs = 1000;
uint16_t penDownUs = 1600;
uint16_t penSettleMs = 250;
bool penIsDown = false;
float penDownThresholdS = 40.0f;
int8_t dirX = 1;
int8_t dirY = 1;

String usbLine;
String bluetoothLine;

void reply(const String &message) {
  Serial.print(message);
#if ENABLE_BLUETOOTH
  SerialBT.print(message);
#endif
}

void replyLine(const String &message) {
  reply(message + "\r\n");
}

void setMotorEnable(bool enabled) {
  motorsEnabled = enabled;
  const uint8_t duty =
      enabled ? static_cast<uint8_t>((FULL_SPEED_PWM * motorPowerPercent) / 100) : 0;
  analogWrite(PIN_PWM_M1, duty);
  analogWrite(PIN_PWM_M2, duty);
  analogWrite(PIN_PWM_M3, duty);
  analogWrite(PIN_PWM_M4, duty);
  if (!enabled) {
    xMotor.release();
    yMotor.release();
  }
}

uint32_t pulseToDuty(uint16_t pulseUs) {
  constexpr uint32_t maxDuty = (1UL << SERVO_RESOLUTION_BITS) - 1;
  return (static_cast<uint32_t>(pulseUs) * maxDuty) / 20000UL;
}

void setPen(bool down) {
  const bool changed = down != penIsDown;
  penIsDown = down;
  ledcWrite(PIN_SERVO, pulseToDuty(down ? penDownUs : penUpUs));
  if (changed) delay(penSettleMs);
}

void coilTest() {
  struct Pulse { const char *name; uint8_t bit; };
  const Pulse pulses[] = {
      {"X M1A", BIT_M1_A}, {"X M1B", BIT_M1_B},
      {"X M2A", BIT_M2_A}, {"X M2B", BIT_M2_B},
      {"Y M3A", BIT_M3_A}, {"Y M3B", BIT_M3_B},
      {"Y M4A", BIT_M4_A}, {"Y M4B", BIT_M4_B},
  };

  replyLine("Coil test: 8 pulses via 74HC595. Expect one twitch each.");
  xMotor.release();
  yMotor.release();
  setMotorEnable(true);
  for (const Pulse &p : pulses) {
    replyLine(String("  ") + p.name);
    latchState = (1u << p.bit);
    latchTx();
    delay(600);
    latchState = 0;
    latchTx();
    delay(250);
  }
  setMotorEnable(false);
  replyLine("Test finished, motors released.");
}

void showStatus() {
  String state = "<Idle|MPos:";
  state += String(xPositionMm, 3) + "," + String(yPositionMm, 3);
  state += "|Pen:" + String(penIsDown ? "Down" : "Up");
  state += "|Motors:" + String(motorsEnabled ? "On" : "Off");
  state += "|Pwr:" + String(motorPowerPercent) + "%>";
  replyLine(state);
}

bool extractValue(const String &line, char code, float &value) {
  for (size_t i = 0; i < line.length(); ++i) {
    if (line[i] != code) continue;
    if (i > 0 && isalpha(static_cast<unsigned char>(line[i - 1]))) continue;
    char *end = nullptr;
    const float parsed = strtof(line.c_str() + i + 1, &end);
    if (end != line.c_str() + i + 1) {
      value = parsed;
      return true;
    }
  }
  return false;
}

int extractIntegerCode(const String &line, char code) {
  float value = 0;
  return extractValue(line, code, value) ? static_cast<int>(lroundf(value)) : -1;
}

void moveLinear(float targetX, float targetY, float feedMmMin) {
  targetX = constrain(targetX, 0.0f, bedMaxX);
  targetY = constrain(targetY, 0.0f, bedMaxY);

  const int32_t targetXSteps = lroundf(targetX * stepsPerMmX);
  const int32_t targetYSteps = lroundf(targetY * stepsPerMmY);
  const int32_t deltaX = targetXSteps - xMotor.positionSteps;
  const int32_t deltaY = targetYSteps - yMotor.positionSteps;
  const int32_t absX = abs(deltaX);
  const int32_t absY = abs(deltaY);
  const int32_t majorSteps = max(absX, absY);

  if (majorSteps == 0) {
    xPositionMm = targetX;
    yPositionMm = targetY;
    return;
  }

  setMotorEnable(true);
  const float distanceMm = hypotf(targetX - xPositionMm, targetY - yPositionMm);
  const float safeFeed = max(feedMmMin, 1.0f);
  const uint32_t intervalUs = max(
      MIN_STEP_INTERVAL_US,
      static_cast<uint32_t>((distanceMm * 60000000.0f) / (safeFeed * majorSteps)));

  int32_t error = absX - absY;
  const int8_t logicalX = deltaX >= 0 ? 1 : -1;
  const int8_t logicalY = deltaY >= 0 ? 1 : -1;

  for (;;) {
    if (xMotor.positionSteps == targetXSteps && yMotor.positionSteps == targetYSteps) break;
    const int32_t twiceError = 2 * error;
    if (twiceError > -absY && xMotor.positionSteps != targetXSteps) {
      error -= absY;
      // dirX/dirY only flip the physical coil sequence; software steps stay logical.
      xMotor.phase = (xMotor.phase + ((logicalX * dirX > 0) ? 1 : 3)) & 0x03;
      xMotor.positionSteps += logicalX;
      xMotor.applyPhase();
    }
    if (twiceError < absX && yMotor.positionSteps != targetYSteps) {
      error += absX;
      yMotor.phase = (yMotor.phase + ((logicalY * dirY > 0) ? 1 : 3)) & 0x03;
      yMotor.positionSteps += logicalY;
      yMotor.applyPhase();
    }
    delayMicroseconds(intervalUs);
  }

  xPositionMm = targetX;
  yPositionMm = targetY;
}

bool setSetting(const String &line, const char *prefix, float &setting) {
  if (!line.startsWith(prefix)) return false;
  const float candidate = line.substring(strlen(prefix)).toFloat();
  if (candidate <= 0.0f) {
    replyLine("error: value must be positive");
  } else {
    setting = candidate;
    replyLine("ok");
  }
  return true;
}

void handleSystemCommand(const String &line) {
  if (line == "$HELP") {
    replyLine("$STATUS $COILTEST $POWER=pct $STEPSX= $STEPSY= "
              "$INVERTX=0|1 $INVERTY=0|1 $PENUP=us $PENDOWN=us "
              "$PENSETTLE=ms $PENTHRESH= $MOTORS=ON|OFF");
    return;
  }
  if (line == "$STATUS" || line == "?") {
    showStatus();
    return;
  }
  if (line == "$COILTEST") {
    coilTest();
    replyLine("ok");
    return;
  }
  if (setSetting(line, "$STEPSX=", stepsPerMmX) || setSetting(line, "$STEPSY=", stepsPerMmY) ||
      setSetting(line, "$PENTHRESH=", penDownThresholdS)) return;

  if (line.startsWith("$INVERTX=")) {
    dirX = line.substring(9).toInt() ? -1 : 1;
    replyLine("ok");
    return;
  }
  if (line.startsWith("$INVERTY=")) {
    dirY = line.substring(9).toInt() ? -1 : 1;
    replyLine("ok");
    return;
  }

  if (line.startsWith("$PENUP=") || line.startsWith("$PENDOWN=")) {
    const bool isUp = line.startsWith("$PENUP=");
    const uint16_t pulse = static_cast<uint16_t>(line.substring(isUp ? 7 : 9).toInt());
    if (pulse < 500 || pulse > 2500) {
      replyLine("error: servo pulse must be 500..2500us");
      return;
    }
    if (isUp) penUpUs = pulse; else penDownUs = pulse;
    setPen(penIsDown);
    replyLine("ok");
    return;
  }

  if (line.startsWith("$POWER=")) {
    const long percent = line.substring(7).toInt();
    if (percent < 5 || percent > 100) {
      replyLine("error: power must be 5..100 percent");
      return;
    }
    motorPowerPercent = static_cast<uint8_t>(percent);
    if (motorsEnabled) setMotorEnable(true);
    replyLine("ok");
    return;
  }

  if (line.startsWith("$PENSETTLE=")) {
    const long settle = line.substring(11).toInt();
    if (settle < 0 || settle > 2000) {
      replyLine("error: pen settle must be 0..2000ms");
      return;
    }
    penSettleMs = static_cast<uint16_t>(settle);
    replyLine("ok");
    return;
  }

  if (line == "$MOTORS=ON") {
    setMotorEnable(true);
    replyLine("ok");
    return;
  }
  if (line == "$MOTORS=OFF") {
    setMotorEnable(false);
    replyLine("ok");
    return;
  }
  replyLine("error: unsupported system command");
}

void executeGcode(String line) {
  line.trim();
  const int comment = line.indexOf(';');
  if (comment >= 0) line.remove(comment);
  line.toUpperCase();
  line.trim();
  if (line.isEmpty()) return;

  if (line[0] == '$' || line == "?") {
    handleSystemCommand(line);
    return;
  }

  const int gCode = extractIntegerCode(line, 'G');
  const int mCode = extractIntegerCode(line, 'M');
  if (mCode == 3 || mCode == 4) {
    setPen(true);
    replyLine("ok");
    return;
  }
  if (mCode == 5) {
    setPen(false);
    replyLine("ok");
    return;
  }
  if (mCode == 2 || mCode == 30) {
    setPen(false);
    setMotorEnable(false);
    replyLine("ok");
    return;
  }
  if (mCode == 300 || mCode == 280) {
    float sValue = 0;
    if (extractValue(line, 'S', sValue)) setPen(sValue <= penDownThresholdS);
    replyLine("ok");
    return;
  }
  if (mCode == 18 || mCode == 84) {
    setMotorEnable(false);
    replyLine("ok");
    return;
  }
  if (mCode == 105) {
    replyLine("ok T:0.0 /0.0 B:0.0 /0.0");
    return;
  }
  if (mCode == 114) {
    replyLine("X:" + String(xPositionMm, 2) + " Y:" + String(yPositionMm, 2) +
              " Z:0.00 E:0.00");
    replyLine("ok");
    return;
  }
  if (gCode == 20) {
    unitScaleMm = 25.4f;
    replyLine("ok");
    return;
  }
  if (gCode == 21) {
    unitScaleMm = 1.0f;
    replyLine("ok");
    return;
  }
  if (gCode == 90) {
    absoluteMode = true;
    replyLine("ok");
    return;
  }
  if (gCode == 91) {
    absoluteMode = false;
    replyLine("ok");
    return;
  }
  if (gCode == 92) {
    float value = 0;
    if (extractValue(line, 'X', value)) xPositionMm = value * unitScaleMm;
    if (extractValue(line, 'Y', value)) yPositionMm = value * unitScaleMm;
    xMotor.positionSteps = lroundf(xPositionMm * stepsPerMmX);
    yMotor.positionSteps = lroundf(yPositionMm * stepsPerMmY);
    replyLine("ok");
    return;
  }
  if (gCode == 28) {
    setPen(false);
    moveLinear(0.0f, 0.0f, RAPID_FEED_MM_MIN);
    replyLine("ok");
    return;
  }
  if (gCode != 0 && gCode != 1) {
    replyLine("echo:ignored " + line);
    replyLine("ok");
    return;
  }

  float xValue = 0;
  float yValue = 0;
  float z = 0;
  float feed = feedRateMmMin;
  const bool hasX = extractValue(line, 'X', xValue);
  const bool hasY = extractValue(line, 'Y', yValue);
  const bool hasZ = extractValue(line, 'Z', z);
  if (extractValue(line, 'F', feed)) feedRateMmMin = feed * unitScaleMm;
  float x = hasX ? xValue * unitScaleMm : xPositionMm;
  float y = hasY ? yValue * unitScaleMm : yPositionMm;
  if (!absoluteMode) {
    if (hasX) x += xPositionMm;
    if (hasY) y += yPositionMm;
  }
  if (hasZ) setPen(z * unitScaleMm <= 0.0f);
  if (hasX || hasY) moveLinear(x, y, gCode == 0 ? RAPID_FEED_MM_MIN : feedRateMmMin);
  replyLine("ok");
}

void consumeInput(Stream &input, String &buffer) {
  while (input.available()) {
    const char character = static_cast<char>(input.read());
    if (character == '\r' || character == '\n') {
      if (!buffer.isEmpty()) {
        executeGcode(buffer);
        buffer = "";
      }
    } else if (buffer.length() < 120) {
      buffer += character;
    } else {
      buffer = "";
      replyLine("error: line too long");
    }
  }
}

#if ENABLE_WIFI
void handleRoot() {
  String page = FPSTR(WEB_UI);
  page.replace("__BED_W__", String(BED_W_MM, 1));
  page.replace("__BED_H__", String(BED_H_MM, 1));
  server.send(200, "text/html", page);
}

void handlePlot() {
  if (jobActive) {
    server.send(409, "text/plain", "already plotting");
    return;
  }
  const String body = server.arg("plain");
  if (body.isEmpty()) {
    server.send(400, "text/plain", "empty drawing");
    return;
  }
  if (body.length() > MAX_JOB_BYTES) {
    server.send(413, "text/plain", "drawing too large");
    return;
  }
  jobBuffer = body;
  jobCursor = 0;
  jobActive = true;
  server.send(200, "text/plain", "plotting");
}

void handleStatus() {
  const int percent = (jobActive && jobBuffer.length() > 0)
                          ? static_cast<int>((100 * jobCursor) / jobBuffer.length())
                          : 0;
  String json = "{\"active\":";
  json += jobActive ? "true" : "false";
  json += ",\"pct\":" + String(percent);
  json += ",\"x\":" + String(xPositionMm, 2);
  json += ",\"y\":" + String(yPositionMm, 2);
  json += ",\"pen\":";
  json += penIsDown ? "true" : "false";
  json += "}";
  server.send(200, "application/json", json);
}

void endJob() {
  jobActive = false;
  jobBuffer = "";
  jobCursor = 0;
  setPen(false);
  setMotorEnable(false);
}

void handleStop() {
  endJob();
  server.send(200, "text/plain", "stopped");
}

void serviceJob() {
  if (!jobActive) return;
  if (jobCursor >= jobBuffer.length()) {
    endJob();
    return;
  }
  int newline = jobBuffer.indexOf('\n', jobCursor);
  if (newline < 0) newline = jobBuffer.length();
  const String line = jobBuffer.substring(jobCursor, newline);
  jobCursor = newline + 1;
  executeGcode(line);
}

void startNetwork() {
  if (strlen(WIFI_SSID) > 0) {
    WiFi.mode(WIFI_STA);
    WiFi.begin(WIFI_SSID, WIFI_PASSWORD);
    for (int i = 0; i < 40 && WiFi.status() != WL_CONNECTED; ++i) delay(250);
  }
  if (WiFi.status() == WL_CONNECTED) {
    replyLine("WiFi joined " + String(WIFI_SSID));
    replyLine("Open http://" + WiFi.localIP().toString());
  } else {
    WiFi.mode(WIFI_AP);
    WiFi.softAP(AP_SSID, AP_PASSWORD);
    replyLine("WiFi hotspot \"" + String(AP_SSID) + "\" password " + String(AP_PASSWORD));
    replyLine("Open http://" + WiFi.softAPIP().toString());
  }
  server.on("/", handleRoot);
  server.on("/plot", HTTP_POST, handlePlot);
  server.on("/status", handleStatus);
  server.on("/stop", HTTP_POST, handleStop);
  server.begin();
}
#endif

void setup() {
  Serial.begin(115200);
#if ENABLE_BLUETOOTH
  SerialBT.begin("DVD_Plotter");
#endif

  shiftBegin();

  pinMode(PIN_PWM_M1, OUTPUT);
  pinMode(PIN_PWM_M2, OUTPUT);
  pinMode(PIN_PWM_M3, OUTPUT);
  pinMode(PIN_PWM_M4, OUTPUT);
  for (uint8_t pin : {PIN_PWM_M1, PIN_PWM_M2, PIN_PWM_M3, PIN_PWM_M4}) {
    analogWriteFrequency(pin, ENABLE_PWM_HZ);
  }
  setMotorEnable(false);

  ledcAttach(PIN_SERVO, SERVO_FREQUENCY_HZ, SERVO_RESOLUTION_BITS);
  setPen(false);

#if ENABLE_WIFI
  startNetwork();
#endif

  replyLine("ESP32 HW-130 plotter ready (74HC595 jumper path)");
  replyLine("Use $HELP; motors start disabled. $COILTEST then $POWER=70");
}

void loop() {
  consumeInput(Serial, usbLine);
#if ENABLE_BLUETOOTH
  consumeInput(SerialBT, bluetoothLine);
#endif
#if ENABLE_WIFI
  server.handleClient();
  serviceJob();
#endif
}

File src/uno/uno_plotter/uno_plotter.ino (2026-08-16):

// Arduino Uno + HW-130 G-code pen plotter.
//
// Uses the stock Adafruit Motor Shield V1 / HW-130 path (74HC595 stays in
// place). Compatible with tools/send_gcode.py, tools/text2gcode.py, and
// tools/handwriting2gcode.py (M300 pen commands).
//
//   arduino-cli compile -b arduino:avr:uno src/uno/uno_plotter
//   arduino-cli upload  -b arduino:avr:uno -p /dev/ttyACM0 src/uno/uno_plotter
//   tools/send_gcode.py -p /dev/ttyACM0 -b 115200 test-square-uno.gcode
//
// Centre both sleds by hand before power-on (no endstops).
// Motors release after M18 / end of job so coils do not cook.

#include <AFMotor.h>
#include <Servo.h>
#include <math.h>

const int STEPS_PER_REV = 20;  // only used by AFMotor's rpm helper
AF_Stepper motorX(STEPS_PER_REV, 1);  // M1 + M2
AF_Stepper motorY(STEPS_PER_REV, 2);  // M3 + M4

Servo penServo;
const uint8_t SERVO_PIN = 10;  // shield SERVO_1 header

// Physical bed from your frame: ~55 mm X, ~70 mm Y. Tune steps/mm with
// $STEPSX= / $STEPSY= after a measured move.
float stepsPerMmX = 2.058f;
float stepsPerMmY = 2.058f;
float bedMaxX = 55.0f;
float bedMaxY = 50.0f;

float xMm = 0.0f;
float yMm = 0.0f;
int32_t xSteps = 0;
int32_t ySteps = 0;

bool absoluteMode = true;
float unitScaleMm = 1.0f;
float feedMmMin = 180.0f;
const float RAPID_MM_MIN = 300.0f;
const uint32_t MIN_STEP_US = 2000;  // ~500 step/s ceiling

int8_t dirX = 1;  // set to -1 with $INVERTX=1 if travel is mirrored
int8_t dirY = 1;

uint8_t stepStyle = SINGLE;
bool motorsOn = false;
bool penIsDown = false;
uint8_t penUpDeg = 60;
uint8_t penDownDeg = 20;
float penDownThresholdS = 40.0f;
uint16_t penSettleMs = 160;
bool servoAttached = false;

String lineBuf;

void reply(const String &s) {
  Serial.println(s);
}

void releaseMotors() {
  motorX.release();
  motorY.release();
  motorsOn = false;
}

void enableMotors() {
  motorsOn = true;
}

void setPen(bool down) {
  if (penIsDown == down) return;
  penIsDown = down;
  if (servoAttached) {
    penServo.write(down ? penDownDeg : penUpDeg);
    delay(penSettleMs);
  }
}

bool extractValue(const String &line, char key, float &out) {
  const int i = line.indexOf(key);
  if (i < 0) return false;
  out = line.substring(i + 1).toFloat();
  return true;
}

int extractCode(const String &line, char key) {
  const int i = line.indexOf(key);
  if (i < 0) return -1;
  return line.substring(i + 1).toInt();
}

void stepAxis(bool isX, int8_t signedStep) {
  if (signedStep == 0) return;
  enableMotors();
  if (isX) {
    const uint8_t d = (signedStep * dirX > 0) ? FORWARD : BACKWARD;
    motorX.step(1, d, stepStyle);
    xSteps += signedStep;
  } else {
    const uint8_t d = (signedStep * dirY > 0) ? FORWARD : BACKWARD;
    motorY.step(1, d, stepStyle);
    ySteps += signedStep;
  }
}

void moveLinear(float targetX, float targetY, float feed) {
  if (targetX < 0) targetX = 0;
  if (targetY < 0) targetY = 0;
  if (targetX > bedMaxX) targetX = bedMaxX;
  if (targetY > bedMaxY) targetY = bedMaxY;

  const int32_t tx = lround(targetX * stepsPerMmX);
  const int32_t ty = lround(targetY * stepsPerMmY);
  int32_t dx = tx - xSteps;
  int32_t dy = ty - ySteps;
  const int32_t adx = abs(dx);
  const int32_t ady = abs(dy);
  const int32_t sx = dx >= 0 ? 1 : -1;
  const int32_t sy = dy >= 0 ? 1 : -1;

  const float distMm = sqrtf((targetX - xMm) * (targetX - xMm) +
                             (targetY - yMm) * (targetY - yMm));
  const int32_t steps = adx > ady ? adx : ady;
  if (steps == 0) {
    xMm = targetX;
    yMm = targetY;
    return;
  }

  float f = feed > 1.0f ? feed : feedMmMin;
  // time for the path at feed (mm/min) → µs per Bresenham tick
  uint32_t stepUs = (uint32_t)((distMm / f) * 60000000.0f / (float)steps);
  if (stepUs < MIN_STEP_US) stepUs = MIN_STEP_US;

  int32_t err = adx - ady;
  int32_t cx = xSteps;
  int32_t cy = ySteps;
  while (cx != tx || cy != ty) {
    const uint32_t t0 = micros();
    const int32_t e2 = err * 2;
    if (e2 > -ady) {
      err -= ady;
      stepAxis(true, (int8_t)sx);
      cx += sx;
    }
    if (e2 < adx) {
      err += adx;
      stepAxis(false, (int8_t)sy);
      cy += sy;
    }
    while ((uint32_t)(micros() - t0) < stepUs) {
      // wait
    }
  }
  xMm = targetX;
  yMm = targetY;
}

bool setSetting(const String &line, const char *prefix, float &dest) {
  if (!line.startsWith(prefix)) return false;
  dest = line.substring(strlen(prefix)).toFloat();
  reply("ok");
  return true;
}

void handleSystem(String line) {
  if (line == "?" || line == "$") {
    reply("steps/mm X:" + String(stepsPerMmX, 3) + " Y:" + String(stepsPerMmY, 3));
    reply("bed " + String(bedMaxX, 1) + " x " + String(bedMaxY, 1) + " mm");
    reply("pos X:" + String(xMm, 2) + " Y:" + String(yMm, 2) +
          (penIsDown ? " pen:down" : " pen:up"));
    reply("style:" + String(stepStyle == SINGLE ? "SINGLE" : "DOUBLE") +
          " invert X:" + String(dirX) + " Y:" + String(dirY));
    reply("ok");
    return;
  }
  if (setSetting(line, "$STEPSX=", stepsPerMmX) ||
      setSetting(line, "$STEPSY=", stepsPerMmY) ||
      setSetting(line, "$BEDX=", bedMaxX) ||
      setSetting(line, "$BEDY=", bedMaxY) ||
      setSetting(line, "$PENTHRESH=", penDownThresholdS)) {
    return;
  }
  if (line.startsWith("$INVERTX=")) {
    dirX = line.substring(9).toInt() ? -1 : 1;
    reply("ok");
    return;
  }
  if (line.startsWith("$INVERTY=")) {
    dirY = line.substring(9).toInt() ? -1 : 1;
    reply("ok");
    return;
  }
  if (line.startsWith("$STYLE=")) {
    stepStyle = (line.substring(7).toInt() >= 2) ? DOUBLE : SINGLE;
    reply("ok");
    return;
  }
  if (line.startsWith("$PENUP=")) {
    penUpDeg = (uint8_t)constrain(line.substring(7).toInt(), 0, 180);
    if (!penIsDown && servoAttached) penServo.write(penUpDeg);
    reply("ok");
    return;
  }
  if (line.startsWith("$PENDOWN=")) {
    penDownDeg = (uint8_t)constrain(line.substring(9).toInt(), 0, 180);
    if (penIsDown && servoAttached) penServo.write(penDownDeg);
    reply("ok");
    return;
  }
  // Move N mm on one axis so you can measure and set steps/mm.
  // After "$CALX=10" and measuring D mm of travel: $STEPSX=(10/D)*current
  if (line.startsWith("$CALX=")) {
    float mm = line.substring(6).toFloat();
    reply("echo:cal X " + String(mm, 2) + " mm — measure travel, then set $STEPSX=");
    moveLinear(xMm + mm, yMm, 120.0f);
    reply("ok");
    return;
  }
  if (line.startsWith("$CALY=")) {
    float mm = line.substring(6).toFloat();
    reply("echo:cal Y " + String(mm, 2) + " mm — measure travel, then set $STEPSY=");
    moveLinear(xMm, yMm + mm, 120.0f);
    reply("ok");
    return;
  }
  reply("echo:ignored " + line);
  reply("ok");
}
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

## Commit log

2026-07-29 Add ESP32 L293D DVD plotter firmware and wiring docs.
    Custom coil-sequencing firmware replaces FluidNC for the HW-130 shield, with socket-plug wiring and a square test job.
    [config.yaml, esp32_l293d_plotter.ino, upload-fluidnc-file.py]
2026-08-04 Add plotter simulation and fix pen-drag on servo moves.
    The toolpath simulator ports the firmware motion logic so jobs can be checked
    before touching hardware. It exposed that setPen returned before the SG90 had
    travelled, so the first millimetres of every stroke were drawn by a moving pen;
    pen changes now settle for a tunable $PENSETTLE interval.
    Wokwi lint also showed GPIO16/17 are exposed as RX2/TX2 on a 30-pin DevKit,
    which the wiring table now records.
    [esp32_l293d_plotter.ino]
2026-08-04 Add parametric OpenSCAD model of the plotter frame and pen bracket.
    Rendering the assembly exposed that both sleds were parallel, so the machine
    could not have plotted; the axes are now perpendicular with the uprights
    clearing the Y sled. Frame heights are derived from the bracket rather than
    guessed, so editing a sled dimension keeps the pen at the paper.
    STL export caught that the pen guide tube was tangent to the back plate rather
    than merged, which is not a manifold solid and would not have sliced.
    [plotter.scad]
2026-08-04 Fix coil SPICE deck and add a step-rate sweep.
    The deck drove the coil from a DC source, so ngspice solved the operating
    point first and the inductor began already energised. That hid the L/R rise
    entirely and made the reported time constant meaningless. Driving from a pulse
    with uic gives the real current, and the sweep shows torque starts falling off
    past roughly 1000 steps/s.
2026-08-08 Add host-compatible G-code, an image converter, a sender, and a build guide.
    The firmware only lifted the pen on Z moves, but every SVG-to-G-code tool uses
    M300, so nothing would have drawn. It also answered unknown commands with an
    error and no ok, which would have hung any streaming host part-way through a
    plot; every line is now acknowledged exactly once.
    Inkscape 0.48 and the Unicorn plugin cannot be installed on a current system,
    so image2gcode.py calls potrace directly, which is the same engine Inkscape
    used for Trace Bitmap. send_gcode.py replaces Pronterface and lifts the pen and
    releases the motors on Ctrl-C.
    [esp32_l293d_plotter.ino, image2gcode.py, send_gcode.py]
2026-08-08 Serve a phone drawing UI over WiFi.
    Draw with a finger in the browser and the ESP32 plots it, with no app to
    install and nothing tied to one phone platform. Bluetooth cannot do this: no
    drawing app emits G-code over serial, and browsers cannot speak Bluetooth
    Classic at all.
    Strokes are simplified in the browser before sending, since a finger drag
    yields hundreds of near-collinear points that would each become a move. The
    job runs one line per loop pass so the server stays responsive and Stop is
    actually heard mid-plot.
    Bluetooth is compiled out by default. Both radios fit, but they share one
    antenna and coexistence costs stability.
    [esp32_l293d_plotter.ino]
2026-08-08 Add a coil wiring self-test.
    Drives each H-bridge output alone so every coil twitches once. A split pair
    across the two terminal blocks otherwise just makes the motor buzz without
    turning, which is hard to diagnose from a failed move.
    [esp32_l293d_plotter.ino]
2026-08-08 Limit coil current in software with $POWER.
    Sizing the supply from coil resistance alone makes the voltage choice an
    irreversible guess: 9 V is destructive at 10 ohm and too weak at 30 ohm, and
    DVD steppers span that whole range. Chopping the enable pins at 20 kHz sets
    average current in software instead, so it starts safe at any resistance and
    can be walked up until the motors move reliably.
    Measuring still gives a better result, but it is no longer required to switch
    on for the first time.
    [esp32_l293d_plotter.ino]
2026-08-08 Cover the soldered-down 74HC595 case.
    Most HW-130 clones solder the shift register rather than socket it, so it
    cannot simply be pulled. It does not need to be: its output-enable is
    active-low with a pull-up, so with no Arduino attached the outputs are already
    high-impedance and the eight direction lines are free to drive. Wires go onto
    the chip's own output legs, which are the same nodes as the L293D inputs.
    Pin mapping verified against Adafruit's AFMotor library rather than memory.
2026-08-08 Make the 74HC595 output-enable tie mandatory.
    Previously claimed the outputs idle high-impedance because of a pull-up. That
    is what Adafruit documents, but a clone parts list shows a 10K pulldown on the
    same net, which would leave the outputs live. Left live, the shift register
    drives the same wires as the ESP32 GPIOs and both push-pull stages fight.
    Tying D7 to 5V overrides either arrangement, so it is now a required step with
    a meter check rather than an optional precaution.
2026-08-08 Add single-stroke text-to-G-code renderer
    Tracing a rendered font gives letter outlines, so the pen draws each
    stroke as a hollow loop that is unreadable at the 3-4 mm character size
    a 35 mm bed forces. Hershey fonts store stroke centrelines instead, so
    the pen follows the path a hand would.
    Vendors five Hershey faces including a joined cursive, and handles word
    wrap, scaling, and bed-overflow warnings.
2026-08-08 Add neural handwriting generation to G-code
    Uses a Graves-style LSTM that predicts pen trajectories directly, so
    nothing has to be rasterised and re-vectorised on the way to G-code.
    Runs on CPU in seconds; no GPU needed.
    The model stops sampling once its attention reaches the final character,
    which on a short line happens at the first step and yields an empty
    result. Pads lines to 16 characters of context and retries, and now
    aborts rather than dropping a line, since a silently missing word would
    otherwise reach paper.
    [handwriting2gcode.py]
2026-08-08 Reject characters the handwriting model cannot write
    The tokeniser maps anything outside its 79-character alphabet to token 0
    rather than raising, so a '$' or '&' made the model draw an arbitrary
    glyph that would only be noticed once it reached paper. Checks the text
    against the checkpoint alphabet up front, with --skip-unsupported to
    drop them deliberately.
    [handwriting2gcode.py]
2026-08-16 Add Uno bring-up sketch for the sleds
    The HW-130 is an Uno shield and runs natively at 5 V, so the mechanics
    can be proven before any soldering to the 74HC595. Doing it in this
    order means a failed move points at the sleds or coil pairing rather
    than at four changed variables at once.
    Serial-driven with no motion at power-on, single-coil drive by default,
    and both motors released after every command.
    [uno_motor_test.ino]
2026-08-16 Add Uno HW-130 G-code plotter firmware
    Finish the machine on the already-working Arduino stack before the
    ESP32 rewiring. Speaks the same G-code / M300 dialect as the laptop
    tools, clamps to the measured 55×70 mm bed, and exposes $CALX/$CALY
    plus $STEPSX/$STEPSY for a measured steps/mm tune.
2026-08-16 Calibrate Uno steps/mm from measured 10→18 mm travel
    Commanded 10 mm produced 18 mm on both axes, so scale by 10/18
    (3.704 steps/mm). Bed stays 55×50 mm.
2026-08-16 Retune steps/mm: 10 mm command measured 15 mm
2026-08-16 Retune steps/mm: 10 mm command measured 12 mm
2026-08-16 Document Uno bring-up findings and sync docs to calibration
    Record 55×50 mm bed, 2.058 steps/mm, coil ohms, and the sim/CAD
    split so previews use the measured machine instead of the old 35 mm
    defaults. Add FINDINGS.md and the Uno console helper.
2026-08-16 Improve offline plot preview for no-pen testing
    Rectangular 55×50 bed, Uno steps/mm as defaults, and --paper for an
    ink-only page view so jobs can be checked without hardware or media.
2026-08-16 Make Uno path documentation and diagrams complete
    Add STATUS/ARCHITECTURE docs, Graphviz system diagrams, paper-preview
    examples, and resize the OpenSCAD bed to the measured 55×50 mm frame.
    Point BUILD and CUSTOM_FIRMWARE at the working Uno path so the repo
    matches what is actually commissioned.
    [plotter.scad]
2026-08-16 Add ESP32 jumper firmware, folder split, and HW-130 adapter PCB.
    Keep Uno and ESP32 firmwares in separate trees, drive the stock 74HC595
    over jumpers (no soldering), and ship a KiCad Uno-form adapter with Gerbers.
    [esp32_hw130_adapter-B_Cu.gbl, esp32_hw130_adapter-B_Mask.gbs, esp32_hw130_adapter-B_Silkscreen.gbo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]
